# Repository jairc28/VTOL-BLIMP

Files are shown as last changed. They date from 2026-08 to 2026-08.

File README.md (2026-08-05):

The project presents the design, mathematical modeling, and embedded implementation of a miniature, indoor VTOL (Vertical Takeoff and Landing) robotic blimp. The vehicle operates under quasi-neutral buoyancy using a 50-inch helium-filled Mylar balloon, which provides the baseline lift.

To minimize payload and complexity, the blimp uses a minimal-sensing architecture managed by an ESP32-C6 microcontroller, relying on a VL53L1X Time-of-Flight sensor for altitude and an MPU6050 IMU for heading estimation. Its propulsion system consists of two counter-rotating coreless DC motors mounted on a 180-degree servo-actuated vectored-thrust mechanism. This design allows the same motors to control both vertical lift and horizontal maneuvering. Ultimately, the paper provides a complete, reproducible engineering design and experimentally identifies the dynamic models for the vehicle's vertical and yaw motions to aid future research in aerial robotics.

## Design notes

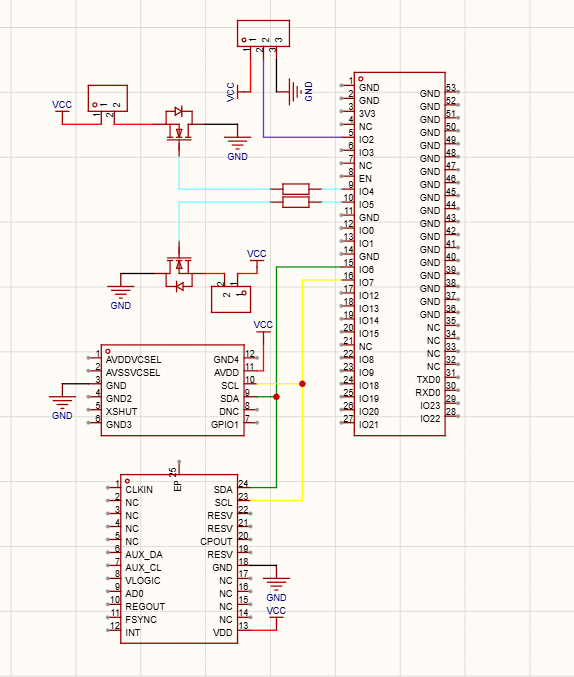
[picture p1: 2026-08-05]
VTOL_BLIMP/hardware/cto_blimp.png

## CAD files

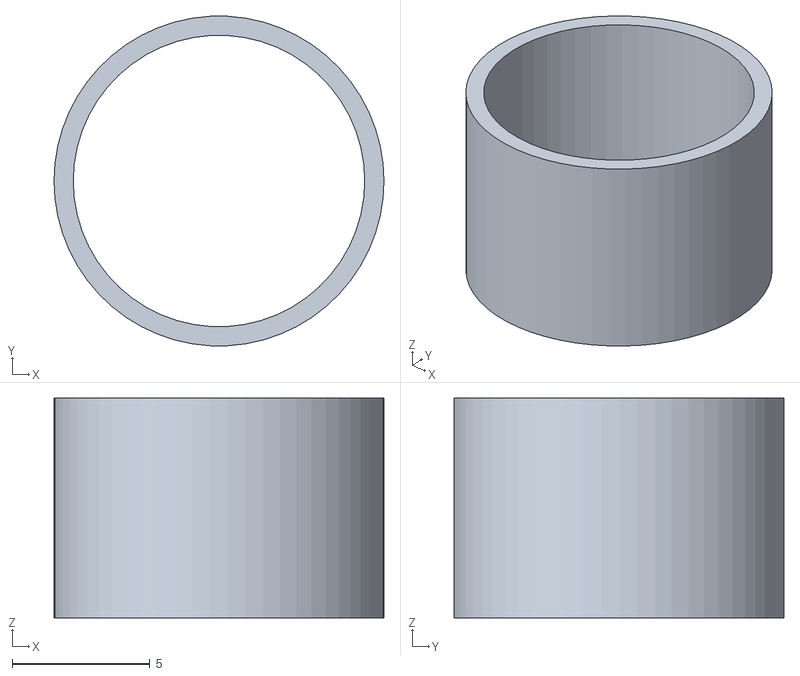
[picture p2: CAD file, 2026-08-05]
VTOL_BLIMP/hardware/impresion3d/tope.STL
12.0 x 12.0 x 8.00

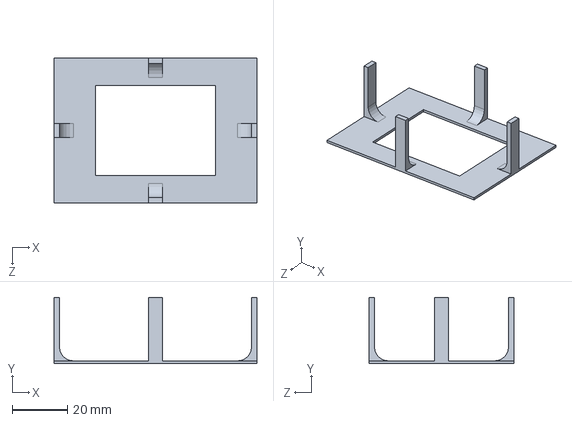
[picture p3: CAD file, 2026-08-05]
VTOL_BLIMP/hardware/techogondola.SLDPRT
73.5 x 24.0 x 52.5 mm

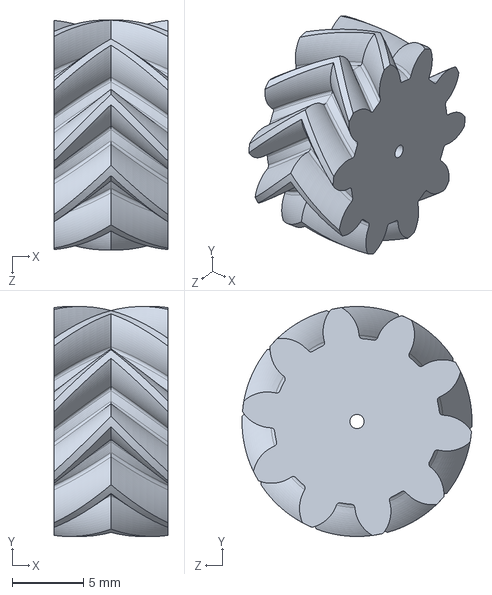
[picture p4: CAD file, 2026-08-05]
VTOL_BLIMP/hardware/piñonservo.SLDPRT
8.00 x 16.1 x 16.1 mm

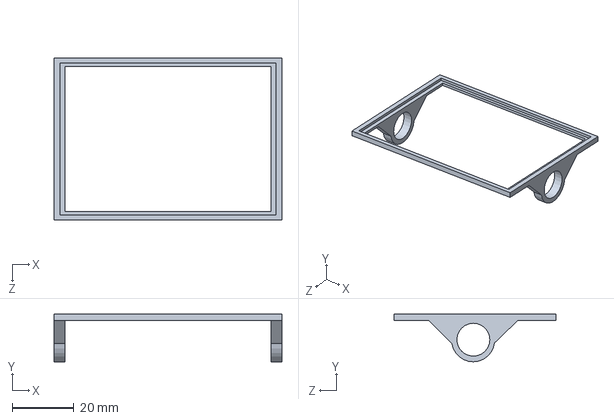
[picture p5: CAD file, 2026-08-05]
VTOL_BLIMP/hardware/gondolabajav4.SLDPRT
74.1 x 15.5 x 52.7 mm

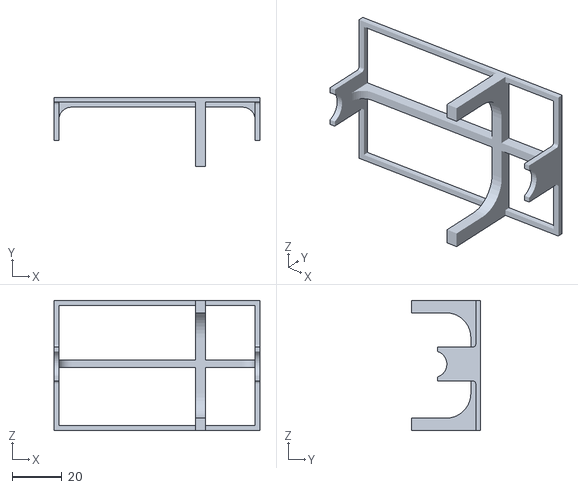
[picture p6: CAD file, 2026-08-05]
VTOL_BLIMP/hardware/impresion3d/pits.STL
83.0 x 28.0 x 52.5

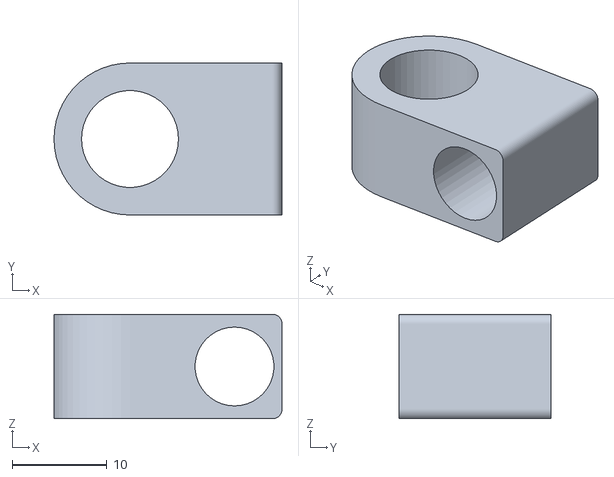
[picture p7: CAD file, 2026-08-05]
VTOL_BLIMP/hardware/impresion3d/sophelice.STL
24.0 x 16.0 x 11.0

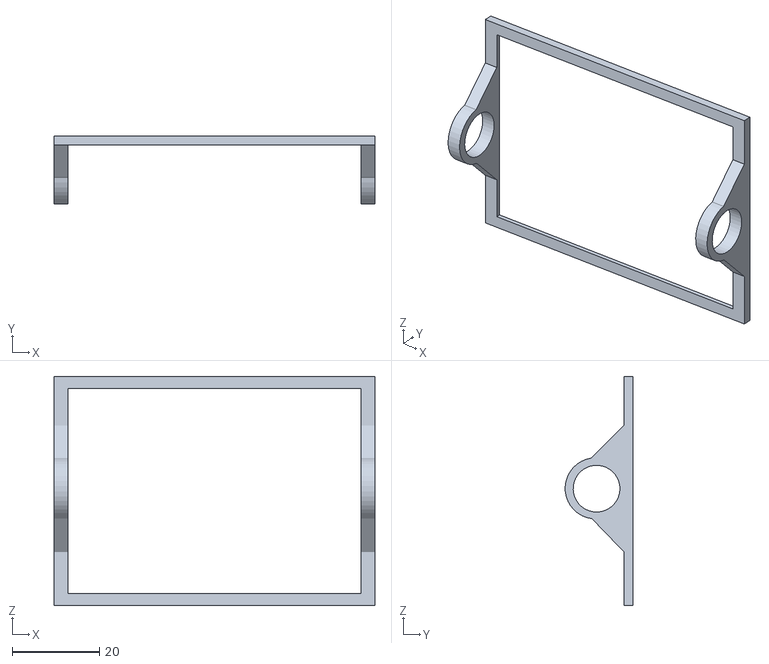
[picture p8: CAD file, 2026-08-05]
VTOL_BLIMP/hardware/impresion3d/gondolabajav4.STL
73.5 x 15.5 x 52.5

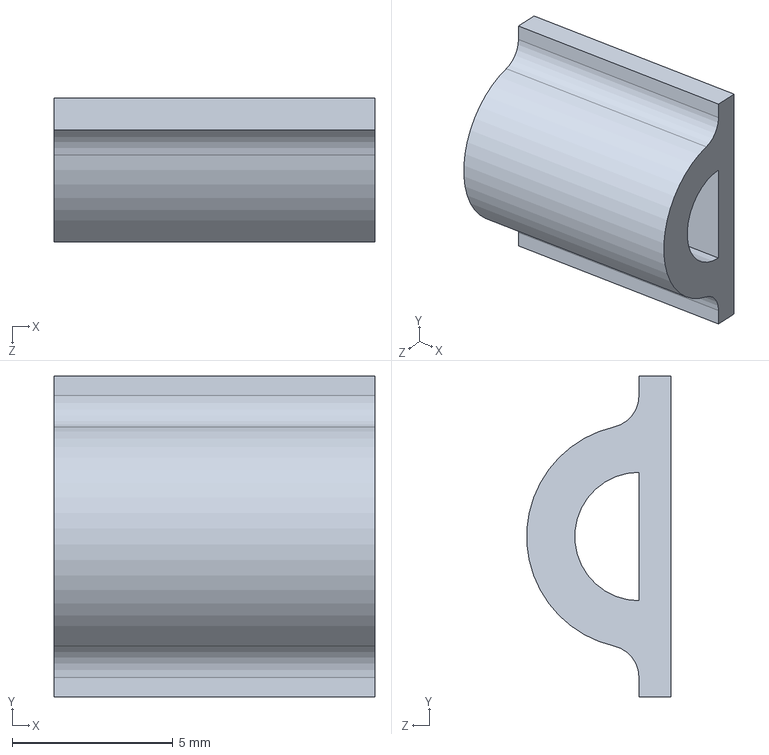
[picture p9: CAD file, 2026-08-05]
VTOL_BLIMP/hardware/guiablimp.SLDPRT
10.0 x 10.0 x 4.49 mm

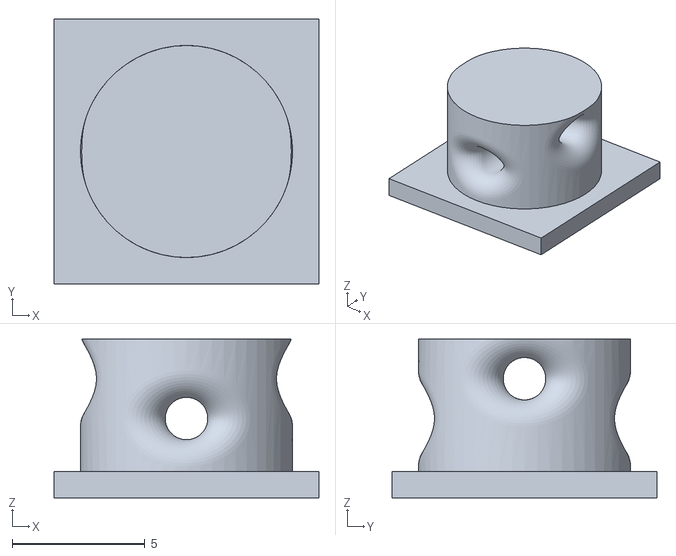
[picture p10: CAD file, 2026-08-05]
VTOL_BLIMP/hardware/impresion3d/topeguiablimp.STL
10.0 x 10.0 x 6.00

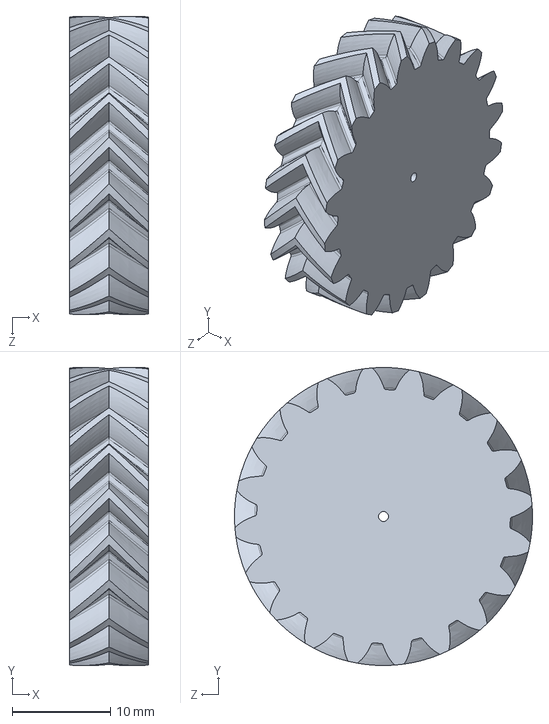
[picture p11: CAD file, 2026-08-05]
VTOL_BLIMP/hardware/pinoneje.SLDPRT
8.00 x 30.3 x 30.3 mm

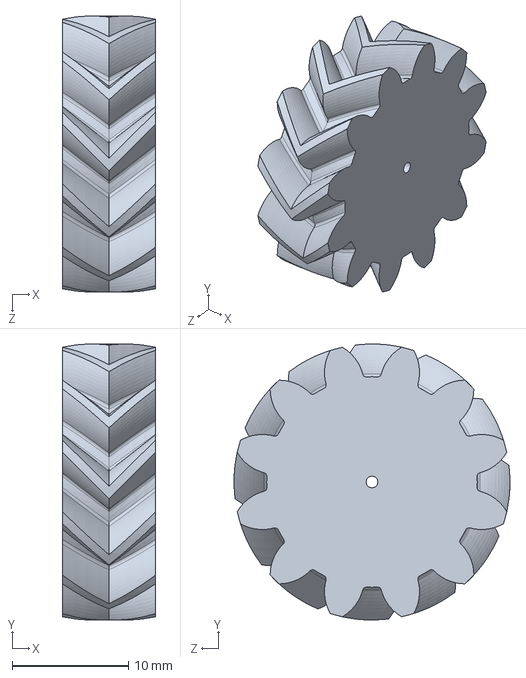
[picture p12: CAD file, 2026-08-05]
VTOL_BLIMP/hardware/piñonsinperfos.SLDPRT
8.00 x 23.7 x 23.7 mm

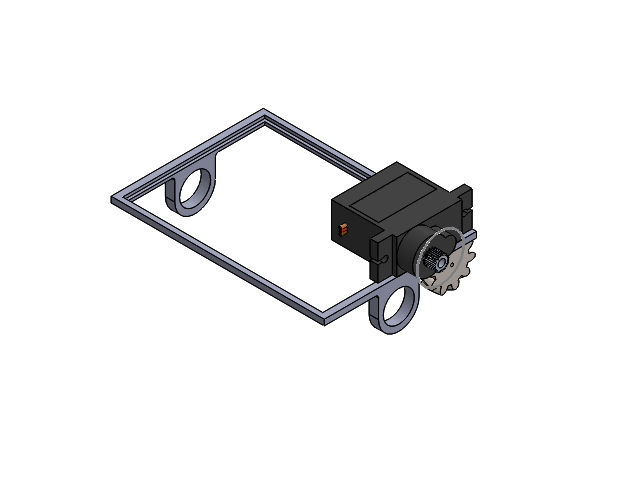
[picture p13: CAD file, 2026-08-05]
VTOL_BLIMP/hardware/Ensamblaje1.SLDASM
gondolabajav2
User Library-MG90
helical gear_3_am

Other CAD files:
VTOL_BLIMP/hardware/impresion3d/techogondola.STL
VTOL_BLIMP/hardware/tope.SLDPRT
VTOL_BLIMP/hardware/impresion3d/guiablimp.STL
VTOL_BLIMP/hardware/topeguiablimp.SLDPRT
VTOL_BLIMP/hardware/pits.SLDPRT
VTOL_BLIMP/hardware/sophelice.SLDPRT

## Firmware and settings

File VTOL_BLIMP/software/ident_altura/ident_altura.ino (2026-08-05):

/*
 * ident_altura.ino — blimp_definitivo/ident_altura
 * ============================================================
 * Controlador PROPORCIONAL de altura para identificación.
 * Sensor: VL53L1X (ToF)
 * Actuador: 2 motores + servo vectorial (embrague mecánico)
 *
 * PROTOCOLO TCP:
 *   MATLAB → ESP32 : "modo,setpoint_mm,K,mapeo\n"
 *                     modo: 0=STOP  1=Proporcional cerrado
 *                     mapeo: 0=directo  1=interpolado [50-255]
 *   ESP32  → MATLAB: "millis,dist_mm,sp_mm,e_m,u_k,pwm,emb\n"
 * ============================================================
 */

#include <WiFi.h>
#include <Wire.h>
#include <VL53L1X.h>

// ── Pines ────────────────────────────────────────────────────
const int motorIzqPin = 4;
const int motorDerPin = 5;
const int servoPin    = 2;
const int sdaPin      = 6;
const int sclPin      = 7;

// ── WiFi ─────────────────────────────────────────────────────
const char* ssid     = "iPhone de HP";
const char* password = "Contra12";
WiFiServer server(80);

// ── Sensor ToF ───────────────────────────────────────────────
VL53L1X sensorTof;
bool    tof_ok = false;

// ── Servo vectorial ──────────────────────────────────────────
const int SERVO_DESPEGAR   = 2000;
const int SERVO_ATERRIZAR  = 400;
const unsigned long TRANSIT_TIME_MS = 350;

// ── Límites PWM ──────────────────────────────────────────────
const float U_MAX     = 255.0f;
const int   PWM_MIN_Z = 50;
const int   PWM_MAX_Z = 255;

// ── Filtro EMA y zona muerta ─────────────────────────────────
const float ERR_DEADBAND_M = 0.015f;
const float ALPHA_EMA      = 0.4f;
float dist_filtrada_m = 0.0f;
bool  primer_muestra  = true;

// ── Estado controlador ───────────────────────────────────────
int   modo         = 0;
bool  mapeo_activo = false;
float sp_mm        = 1000.0f;
float K_coef       = 1.0f;     // Ganancia proporcional

int   offset_izq   = 10;
int   offset_der   = 10;

uint16_t last_valid_dist    = 0;
int      error_sensor_count = 0;
const int MAX_SENSOR_ERRORS = 5;

// ── Embrague ─────────────────────────────────────────────────
enum EstadoEmbrague { EMB_IDLE, EMB_MOVING, EMB_ON };
EstadoEmbrague estadoEmbrague  = EMB_IDLE;
int            direccionActual = SERVO_DESPEGAR;
unsigned long  t_transit_ini   = 0;

// ── Temporización ────────────────────────────────────────────
const unsigned long T_MS = 500;
unsigned long last_ctrl_ms     = 0;
bool          modo_inicializado = false;

// ── Prototipos ───────────────────────────────────────────────
bool leerToF(uint16_t& d);
void loopPropAltura(WiFiClient& c);
bool leerComando(WiFiClient& c);
void enviarTelemetria(WiFiClient& c, uint16_t dist, float sp_tel, float e_m, float u_k, int pwm);
int  mapearPWM(float u_abs, bool usar_mapeo);
void resetCtrl();

// ─────────────────────────────────────────────────────────────
void setup() {
  Serial.begin(115200);
  Wire.begin(sdaPin, sclPin);

  pinMode(motorIzqPin, OUTPUT); pinMode(motorDerPin, OUTPUT);
  analogWrite(motorIzqPin, 0); analogWrite(motorDerPin, 0);

  ledcAttach(servoPin, 50, 14);
  ledcWrite(servoPin, SERVO_DESPEGAR);

  for (int i = 1; i <= 3 && !tof_ok; i++) {
    delay(100);
    sensorTof.setTimeout(500);
    if (sensorTof.init()) {
      sensorTof.setDistanceMode(VL53L1X::Long);
      sensorTof.setMeasurementTimingBudget(50000);
      sensorTof.startContinuous(50);
      delay(200);
      tof_ok = true;
      Serial.printf("[ToF] OK (intento %d)\n", i);
    } else {
      Serial.printf("[ToF] Intento %d fallido\n", i);
    }
  }
  if (!tof_ok) Serial.println("[ToF] ERROR");

  WiFi.mode(WIFI_STA);
  WiFi.begin(ssid, password);
  Serial.print("[WiFi] Conectando");
  while (WiFi.status() != WL_CONNECTED) { delay(500); Serial.print("."); }
  Serial.printf("\n[WiFi] IP: %s\n", WiFi.localIP().toString().c_str());
  server.begin();
  Serial.println("[Server] Puerto 80 listo — ident_altura");
}

// ─────────────────────────────────────────────────────────────
void loop() {
  WiFiClient client = server.available();
  if (!client) return;

  client.setNoDelay(true);
  Serial.println("[TCP] Cliente conectado");
  modo = 0; modo_inicializado = false; mapeo_activo = false;
  resetCtrl();
  analogWrite(motorIzqPin, 0); analogWrite(motorDerPin, 0);
  ledcWrite(servoPin, SERVO_DESPEGAR);

  while (client.connected()) {
    leerComando(client);
    if (millis() - last_ctrl_ms >= T_MS) {
      last_ctrl_ms = millis();
      if (modo == 1) {
        loopPropAltura(client);
      } else {
        analogWrite(motorIzqPin, 0); analogWrite(motorDerPin, 0);
        ledcWrite(servoPin, SERVO_DESPEGAR);
        estadoEmbrague = EMB_IDLE;
        uint16_t dist = 0; leerToF(dist);
        enviarTelemetria(client, dist ? dist : 8190, sp_mm, 0.0f, 0.0f, 0);
      }
    }
  }

  analogWrite(motorIzqPin, 0); analogWrite(motorDerPin, 0);
  ledcWrite(servoPin, SERVO_DESPEGAR);
  resetCtrl();
  Serial.println("[TCP] Cliente desconectado");
}

// ── leerComando — "modo,setpoint_mm,K,mapeo\n" ──────────────
bool leerComando(WiFiClient& client) {
  if (client.available() > 0) {
    String ultimo = client.readStringUntil('\n');
    ultimo.trim();
    client.flush();
    if (ultimo.length() == 0) return false;

    int c1 = ultimo.indexOf(',');
    int c2 = ultimo.indexOf(',', c1+1);
    int c3 = ultimo.indexOf(',', c2+1);
    int c4 = ultimo.indexOf(',', c3+1);
    int c5 = ultimo.indexOf(',', c4+1);
    
    if (c1 < 0 || c3 < 0) return false;

    int   nuevo_modo  = ultimo.substring(0,    c1).toInt();
    float nuevo_sp    = ultimo.substring(c1+1, c2).toFloat();
    float nuevo_K     = ultimo.substring(c2+1, c3).toFloat();
    bool  nuevo_mapeo = ultimo.substring(c3+1, c4 > 0 ? c4 : ultimo.length()).toInt() != 0;
    
    if (c4 > 0) {
        offset_izq = ultimo.substring(c4+1, c5 > 0 ? c5 : ultimo.length()).toInt();
        if (c5 > 0) {
            offset_der = ultimo.substring(c5+1).toInt();
        }
    }

    if (nuevo_modo != modo) {
      resetCtrl(); modo = nuevo_modo; modo_inicializado = false;
      Serial.printf("[MODO] → %d\n", modo);
    }
    sp_mm        = nuevo_sp;
    K_coef       = nuevo_K;
    mapeo_activo = nuevo_mapeo;
    return true;
  }
  return false;
}

// ── leerToF ──────────────────────────────────────────────────
bool leerToF(uint16_t& dist_out) {
  if (!tof_ok) { error_sensor_count = MAX_SENSOR_ERRORS; return false; }
  uint16_t dr = sensorTof.read();
  if (sensorTof.timeoutOccurred() || dr == 0 || dr > 6000) {
    error_sensor_count++; dist_out = last_valid_dist; return false;
  }
  if (last_valid_dist > 0 && abs((int)dr - (int)last_valid_dist) > 500) {
    error_sensor_count++; dist_out = last_valid_dist; return false;
  }
  error_sensor_count = 0; last_valid_dist = dr; dist_out = dr;
  return true;
}

// ── resetCtrl ────────────────────────────────────────────────
void resetCtrl() {
  error_sensor_count = 0; estadoEmbrague = EMB_IDLE;
  direccionActual = SERVO_DESPEGAR;
  primer_muestra = true; dist_filtrada_m = 0.0f;
}

// ── mapearPWM ─────────────────────────────────────────────────
int mapearPWM(float u_abs) {
  if (u_abs < 1.0f) return 0;
  if (u_abs > U_MAX) u_abs = U_MAX;
  
  // Mapeo Lineal (Interpolación) para eliminar la onda cuadrada
  int pwm = map((int)u_abs, 1, (int)U_MAX, PWM_MIN_Z, PWM_MAX_Z);
  return pwm;
}

// ── loopPropAltura ───────────────────────────────────────────
void loopPropAltura(WiFiClient& client) {
  if (!modo_inicializado) {
    resetCtrl(); modo_inicializado = true;
    Serial.printf("[P] SP=%.0fmm K=%.4f Mapeo=%s\n",
                  sp_mm, K_coef, mapeo_activo?"SI":"NO");
  }

  uint16_t dist_mm_raw = 0;
  bool ok = leerToF(dist_mm_raw);
  if (!ok && error_sensor_count >= MAX_SENSOR_ERRORS) {
    analogWrite(motorIzqPin, 0); analogWrite(motorDerPin, 0);
    ledcWrite(servoPin, SERVO_DESPEGAR); estadoEmbrague = EMB_IDLE;
    enviarTelemetria(client, 8190, sp_mm, 0.0f, 0.0f, 0);
    return;
  }

  uint16_t dist_mm    = dist_mm_raw ? dist_mm_raw : last_valid_dist;
  float    dist_m_raw = (float)dist_mm / 1000.0f;
  if (primer_muestra) { dist_filtrada_m = dist_m_raw; primer_muestra = false; }
  else { dist_filtrada_m = ALPHA_EMA * dist_m_raw + (1.0f - ALPHA_EMA) * dist_filtrada_m; }

  float sp_m = sp_mm / 1000.0f;
  float e_k  = sp_m - dist_filtrada_m;

  if (fabsf(e_k) < ERR_DEADBAND_M) {
    analogWrite(motorIzqPin, 0); analogWrite(motorDerPin, 0);
    enviarTelemetria(client, dist_mm, sp_mm, e_k, 0.0f, 0);
    return;
  }

  // Proporcional puro: u = K * e
  float u_k     = K_coef * e_k;
  float u_k_sat = constrain(u_k, -U_MAX, U_MAX);

  // u>=0 (subir) → SERVO_DESPEGAR | u<0 (bajar) → SERVO_ATERRIZAR
  int   nueva_dir = (u_k_sat >= 0.0f) ? SERVO_DESPEGAR : SERVO_ATERRIZAR;
  float u_abs     = fabsf(u_k_sat);
  int   pwm_cmd   = mapeo_activo ? mapearPWM(u_abs) : (int)constrain(u_abs, 0.0f, (float)U_MAX);
  int   pwm_izq   = pwm_cmd;
  int   pwm_der   = pwm_cmd;
  if (!mapeo_activo && pwm_cmd > 0) {
    pwm_izq = constrain(pwm_cmd + offset_izq, offset_izq, 255);
    pwm_der = constrain(pwm_cmd + offset_der, offset_der, 255);
  }

  switch (estadoEmbrague) {
    case EMB_IDLE:
      if (nueva_dir == direccionActual) {
        estadoEmbrague = EMB_ON;
        analogWrite(motorIzqPin, pwm_izq); analogWrite(motorDerPin, pwm_der);
        enviarTelemetria(client, dist_mm, sp_mm, e_k, u_k_sat, pwm_cmd);
      } else {
        direccionActual = nueva_dir; ledcWrite(servoPin, direccionActual);
        t_transit_ini = millis(); estadoEmbrague = EMB_MOVING;
        analogWrite(motorIzqPin, 0); analogWrite(motorDerPin, 0);
        enviarTelemetria(client, dist_mm, sp_mm, e_k, u_k_sat, 0);
      }
      break;
    case EMB_MOVING:
      analogWrite(motorIzqPin, 0); analogWrite(motorDerPin, 0);
      if (millis() - t_transit_ini >= TRANSIT_TIME_MS) estadoEmbrague = EMB_ON;
      enviarTelemetria(client, dist_mm, sp_mm, e_k, u_k_sat, 0);
      break;
    case EMB_ON:
      if (nueva_dir != direccionActual) {
        analogWrite(motorIzqPin, 0); analogWrite(motorDerPin, 0);
        direccionActual = nueva_dir; ledcWrite(servoPin, direccionActual);
        t_transit_ini = millis(); estadoEmbrague = EMB_MOVING;
        enviarTelemetria(client, dist_mm, sp_mm, e_k, u_k_sat, 0);
        break;
      }
      analogWrite(motorIzqPin, pwm_izq); analogWrite(motorDerPin, pwm_der);
      enviarTelemetria(client, dist_mm, sp_mm, e_k, u_k_sat, pwm_cmd);
      Serial.printf("[P] e=%.4f u=%.2f pwm=%d %s\n",
                    e_k, u_k_sat, pwm_cmd, mapeo_activo?"[MAP]":"[DIR]");
      break;
  }
}

// ── enviarTelemetria ─────────────────────────────────────────
void enviarTelemetria(WiFiClient& client, uint16_t dist, float sp_tel,
                      float e_m, float u_k, int pwm) {
  client.printf("%lu,%d,%.0f,%.4f,%.3f,%d,%d\n",
    millis(), dist, sp_tel, e_m, u_k, pwm, (int)estadoEmbrague);
}

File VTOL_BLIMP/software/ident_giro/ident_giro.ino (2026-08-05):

/*
 * ident_giro.ino — blimp_definitivo/ident_giro
 * ============================================================
 * Identificación de giro (Yaw) — dos modos:
 *   Modo 1: Lazo ABIERTO  — pulsos alternos con N ciclos
 *   Modo 2: Lazo CERRADO  — control proporcional K
 *
 * IMU: MPU6050
 * Giro positivo → Motor IZQ | Giro negativo → Motor DER
 *
 * PROTOCOLO TCP:
 *   MATLAB → ESP32 :
 *     Modo 0 (STOP):      "0,0,0,0,0\n"
 *     Modo 1 (LA):        "1,pwm,t_on_s,t_off_s,n_ciclos\n"
 *     Modo 2 (LC K):      "2,sp_deg,K,mapeo,0\n"
 *                          mapeo: 0=directo 1=interpolado
 *   ESP32 → MATLAB:
 *     "millis,yaw,sp_o_pwm,e_o_fase,u_k,pwm_izq,pwm_der,omega,fase\n"
 * ============================================================
 */

#include <WiFi.h>
#include <Wire.h>
#include <Adafruit_MPU6050.h>
#include <Adafruit_Sensor.h>

// ── Pines ────────────────────────────────────────────────────
const int motorIzqPin = 4;
const int motorDerPin = 5;
const int servoPin    = 2;
const int sdaPin      = 6;
const int sclPin      = 7;
const int SERVO_HORIZONTAL = 1300;

// ── WiFi ─────────────────────────────────────────────────────
const char* ssid     = "iPhone de HP";
const char* password = "Contra12";
WiFiServer server(80);

// ── IMU ──────────────────────────────────────────────────────
Adafruit_MPU6050 mpu;
bool  mpu_ok          = false;
float gyroZ_offset    = 0.0f;
float yaw_angle       = 0.0f;
float omega_z_dps     = 0.0f;
unsigned long t_ultimo_imu_us = 0;

// ── Límites PWM ──────────────────────────────────────────────
const float U_MAX     = 255.0f;
const int   PWM_MIN_Z = 50;
const int   PWM_MAX_Z = 255;

// ── Zona muerta (lazo cerrado) ───────────────────────────────
const float ERR_DEADBAND_DEG = 2.0f;

// ── Estado general ───────────────────────────────────────────
int   modo         = 0;
bool  mapeo_activo = false;
bool  modo_inicializado = false;

// ── Parámetros Modo 1 (Lazo Abierto) ────────────────────────
float ol_pwm        = 50.0f;  // PWM de prueba configurable
float ol_t_on_s     = 20.0f;  // 20s motor encendido
float ol_t_off_s    = 20.0f;  // 20s reposo
int   ol_n_ciclos   = 3;      // número de ciclos (IZQ ON -> OFF -> DER ON -> OFF)

// Máquina de estados OL:
// fase 0: IZQ ON | fase 1: REPOSO | fase 2: DER ON | fase 3: REPOSO
// Se repite ol_n_ciclos veces, luego fase=99 (DONE)
int           ol_fase        = 99;
int           ol_ciclo_actual = 0;
unsigned long ol_fase_ini_ms = 0;

// ── Parámetros Modo 2 (Proporcional K) ──────────────────────
float sp_deg   = 90.0f;   // Setpoint por defecto a 90 grados
float K_coef   = -0.5f;   // Ganancias típicas: -0.5 o -0.7

// ── Temporización ────────────────────────────────────────────
const unsigned long T_MS = 50;   // 20 Hz
unsigned long last_ctrl_ms = 0;

// ── Prototipos ───────────────────────────────────────────────
void  calibrarMPU();
void  actualizarIMU();
float wrapAngle(float a);
void  mapearActuadores(float u_k, bool usar_mapeo, int& izq, int& der);
void  loopLazoAbierto(WiFiClient& c);
void  loopProporcional(WiFiClient& c);
bool  leerComando(WiFiClient& c);
void  enviarTelemetria(WiFiClient& c, float yaw, float sp_o_pwm,
                       float e_o_fase, float u_k, int izq, int der,
                       float omega, int fase);
void  stopMotores();

// ─────────────────────────────────────────────────────────────
void setup() {
  Serial.begin(115200);
  Wire.begin(sdaPin, sclPin);

  pinMode(motorIzqPin, OUTPUT); pinMode(motorDerPin, OUTPUT);
  analogWrite(motorIzqPin, 0); analogWrite(motorDerPin, 0);

  ledcAttach(servoPin, 50, 14);
  ledcWrite(servoPin, SERVO_HORIZONTAL);

  if (mpu.begin()) {
    mpu.setAccelerometerRange(MPU6050_RANGE_8_G);
    mpu.setGyroRange(MPU6050_RANGE_500_DEG);
    mpu.setFilterBandwidth(MPU6050_BAND_94_HZ);
    calibrarMPU();
  } else {
    Serial.println("[MPU] ERROR — verificar I2C");
  }

  WiFi.mode(WIFI_STA);
  WiFi.begin(ssid, password);
  Serial.print("[WiFi] Conectando");
  while (WiFi.status() != WL_CONNECTED) { delay(500); Serial.print("."); }
  Serial.printf("\n[WiFi] IP: %s\n", WiFi.localIP().toString().c_str());
  server.begin();
  Serial.println("[Server] Puerto 80 listo — ident_giro");
}

// ─────────────────────────────────────────────────────────────
void calibrarMPU() {
  Serial.println("[MPU] Calibrando 5s — NO mover.");
  float acc = 0.0f;
  const int N = 500;
  for (int i = 0; i < N; i++) {
    sensors_event_t a, g, temp;
    mpu.getEvent(&a, &g, &temp);
    acc += g.gyro.z;
    delay(10);
    if (i % 100 == 0) Serial.printf("  %d%%\n", i*100/N);
  }
  gyroZ_offset = acc / (float)N;
  mpu_ok = true; yaw_angle = 0.0f; t_ultimo_imu_us = 0;
  Serial.printf("[MPU] OK gyroZ_offset=%.5f rad/s\n", gyroZ_offset);
}

// ─────────────────────────────────────────────────────────────
void actualizarIMU() {
  if (!mpu_ok) return;
  unsigned long ahora_us = micros();
  
  float dt = (t_ultimo_imu_us == 0) ? 0.05f :
             (float)(ahora_us - t_ultimo_imu_us) / 1e6f;
  if (dt < 0.001f || dt > 0.5f) dt = 0.05f;
  t_ultimo_imu_us = ahora_us;

  sensors_event_t a, g, temp;
  mpu.getEvent(&a, &g, &temp);
  float gz = g.gyro.z - gyroZ_offset;
  omega_z_dps = gz * (180.0f / PI);

  if (fabsf(gz) < 10.0f) {
    float nuevo = yaw_angle + gz * dt * (180.0f / PI);
    while (nuevo >  180.0f) nuevo -= 360.0f;
    while (nuevo < -180.0f) nuevo += 360.0f;
    yaw_angle = nuevo;
  }
}

// ─────────────────────────────────────────────────────────────
void loop() {
  actualizarIMU();
  WiFiClient client = server.available();
  if (!client) { delay(10); return; }

  client.setNoDelay(true);
  Serial.println("[TCP] Cliente conectado");
  modo = 0; modo_inicializado = false; mapeo_activo = false;
  ol_fase = 99; ol_ciclo_actual = 0;
  stopMotores();

  while (client.connected()) {
    leerComando(client);
    if (millis() - last_ctrl_ms >= T_MS) {
      actualizarIMU();
      last_ctrl_ms = millis();
      switch (modo) {
        case 1: loopLazoAbierto(client);  break;
        case 2: loopProporcional(client); break;
        default:
          stopMotores();
          enviarTelemetria(client, yaw_angle, 0.0f, 0.0f, 0.0f, 0, 0, omega_z_dps, 99);
          break;
      }
    }
    delay(1);
  }

  stopMotores();
  Serial.println("[TCP] Cliente desconectado");
}
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
